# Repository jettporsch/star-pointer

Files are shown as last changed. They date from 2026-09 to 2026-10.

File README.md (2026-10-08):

# Star Pointer

A two-axis motorized mount that points a laser at any star you pick on your
laptop. It works out where to aim from your location, the current time, and a
two-star alignment done at setup.

**Status:** working prototype. After a two-star alignment it points the laser 
at a selected star, controlled from a phone or laptop. Next up is measuring 
accuracy across the sky and a cleaner v2 mount.

**Design target:** ±0.5° pointing accuracy.

## Why I built this

I've always been fascinated with space and astronomy, and I wanted a personal
project that used something I'm passionate about while digging into hardware.
This one covers embedded firmware, motion control, PCB design, mechanical
design, and enough math that the software side isn't just connecting 
libraries together.

## Architecture

This project splits into four jobs: find the star, know where the mount is
actually pointed, convert angles to steps, and generate the pulses.

Pulse generation has to be on the STM32 for microsecond timing and an
instant stop. The astronomy has to be on the laptop, because that's
where the catalog and the UI live.

Step conversion lives in Python for now. Two-star alignment needs the same 
math anyway, and prototyping it in Python was faster to debug. The firmware 
stays simple: it takes step moves, reports position, and handles the laser 
and stop. Porting the conversion to the STM32 is a possible later step.

The interface between the two sides is a small text command set over USB 
serial: move, status, stop, and laser.

```
  Laptop (Python)                    STM32                   Mechanics
  ---------------                    -----                   ---------
  star catalog          USB serial   command parser          NEMA 17 x2
  RA/Dec -> Alt/Az      -------->    step generation  ---->  4:1 GT2 belt
  two-star alignment    <--------    position count          alt-az fork
  angles -> steps        status      laser + auto-off        laser
  web UI (phone/laptop)              stop
```

## Repo layout

| Path | Contents |
|---|---|
| `app/` | Python host application |
| `firmware/` | STM32 firmware |
| `hardware/` | BOM, dimensions, CAD files, bench notes |
| `docs/` | Design decisions, error budget, serial protocol |

## Running the coordinate engine

Standard library only, no install step.

```bash
cd app
python3 skycoords.py        # current alt/az for every catalog star
python3 test_skycoords.py   # validation suite
```

## Running the mount

Needs Flask and pyserial: `pip3 install flask pyserial`.

```bash
python3 -m app.align   # desk test: simulated tilted mount, no hardware needed
python3 -m app.web     # web UI on http://localhost:8000
```

The web app listens on the local network, so a phone on the same wifi can open
it at the laptop's IP address on port 8000.

## Using it outside

1. Stage facing roughly south. That puts the cable limit (half a turn either
   way) due north, where few stars cross. The laser can rest at any angle.
2. 12V on first, so the motors lock the mount in place, then start the web app.
3. Jog the beam onto a bright star, sighting straight down the beam from behind
   the laser, pick it in the Align list, and tap "Beam is on this star."
4. The Align list now ranks every other star as a partner for the first one.
   Pick one rated "good" and do the same.
5. Tap any star in the list to point at it.

Choosing the second star matters more than it looks. With the same 0.1°
centering slip, a good pair keeps every GOTO within about 0.1°, while a poor
one can throw some off by several degrees. The app simulates each pair and
rates it, so there's nothing to memorize.

**Measuring accuracy:** after a GOTO, jog the beam onto the star and tap
"Centered." The app logs how far the GOTO landed from the star, and in which
direction, to `data/accuracy.csv`, and shows the RMS and worst miss for the
current alignment. Alignment stars are logged but left out of the stats.

Never point it at aircraft. The laser turns itself off 60 seconds after the
last command if the app goes away.

## Results so far

- **Step scale and backlash (wall test at 2.9 m):** 100 steps moved the beam
  2.8° on both axes, matching the gear math. Repeated moves with direction
  reversals landed back within about half a millimeter, under 0.01°.
- **First on-sky GOTO (Oct 6, 2026):** aligned on Altair and Vega from a
  driveway sloped about 4°. Alignment reported the base 3° off level and the
  laser's starting angle within 0.1°, both matching the real setup. GOTO to
  Deneb and Polaris landed on the star with no manual correction.
- **Not yet measured:** pointing error in degrees across the sky.

Details in `hardware/bench-notes.md`.

## Validation

The transform is checked against physical facts rather than against another
library. If a check fails, its name points at the specific thing that broke.
Comparing to a reference implementation would only tell me the two disagree,
not where or which one is wrong.

14 checks, all passing.

## References

Sidereal time, Julian date, and precession formulas follow Meeus,
*Astronomical Algorithms*. Refraction uses Bennett's formula.

## Progress

- [x] RA/Dec to alt/az transform, precession, refraction
- [x] Validation suite
- [x] STM32 stepper control, both axes
- [x] Altitude homing
- [x] Prototype mount built
- [x] Azimuth zero (manual index mark; switch homing kept as a test tool)
- [x] Serial protocol spec
- [x] Laser wiring and interlock
- [x] Laser auto-off timer
- [x] Two-star alignment
- [x] End-to-end GOTO
- [ ] Accuracy measurement across the sky
- [ ] v2 mount: smaller frame, cable routing, electronics enclosure
- [ ] Sidereal tracking
- [ ] Custom PCB

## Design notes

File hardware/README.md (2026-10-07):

Parts list in `bom.md`, measured part dimensions in `dimensions.md`, and a dated
log of every bench test in `bench-notes.md`.

CAD files in `cad/`: the full assembly as STEP, plus print files for the parts
changed most recently. No PCB yet; the electronics are on a breadboard.

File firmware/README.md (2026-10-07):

STM32 firmware for a Nucleo-F401RE. Toolchain: STM32CubeIDE.

Takes step moves over USB serial, runs both axes from hardware timers, and
switches the laser. Command set is in `docs/serial-protocol.md`.

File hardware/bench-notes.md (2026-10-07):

# Bench Notes

## 2026-09-15: First stepper test

The motor is rated at 1.5A. Coil pairs are black/blue and green/red.

The driver is a DRV8825 with R100 sense resistors, so I = Vref × 2. I set Vref to 0.595V, which is about 1.19A, 80% of the rating.

SLEEP floated low on this board, so SLEEP and RESET are tied to 3V3 on the Nucleo.

STEP is on PB4 and DIR is on PB5.

I tested one revolution forward and back at 5ms per step, and it worked.

The only problem I hit was that SLEEP floated low, which kept Vref reading 0 until it was tied to 3V3.

## 2026-09-15: Second stepper test

The second driver's Vref is 0.603V, which is about 1.21A. Its 12V, 3V3, and ground all come from driver 1's rows.

Motor 2 pins: STEP2 is on PB10 (D6) and DIR2 is on PA8 (D7). I renamed the first motor's pins to STEP1 and DIR1.

I moved the step loop into a step_motor() function.

Driver 1's heatsink got hot after running motor 1 for around a minute, so I left motor 1 unplugged while setting driver 2.

I tested both motors one revolution forward and back, and it worked.

## 2026-09-15: Serial link test

Serial runs over USART2 through the ST-Link USB at 115200 baud. I read it with screen on the Mac.

First I tested sending hello every second. Then I used keys 1 to 4 to move each motor forward or backward one revolution. The Nucleo replies with what it did.

I added a uart_print() helper.

## 2026-09-15: Hardware timer step pulses

I switched step pulses from bit-banging to hardware timers. TIM3 CH1 on PB4 drives motor 1 and TIM2 CH3 on PB10 drives motor 2.

The timer clock is 84 MHz. Prescaler 83 gives 1 MHz, and period 4999 gives 5ms per step at 50% duty.

An interrupt at the end of each pulse counts down the steps and stops the timer at zero. Each motor is an Axis struct.

I tested both motors moving at once, and that worked. A second command mid-move replies with busy.

CubeMX overwrote the STEP1/STEP2 labels when I assigned the timer channels.

## 2026-09-16: Serial command protocol

The firmware now reads full lines over serial, with echo and backspace.

Commands:
- `M <axis> <steps>` moves axis 1 or 2 by a step count, negative for reverse
- `S` reports position and busy for both axes
- `X` stops both axes

Replies are `OK`, `ERR <reason>`, or data.

Position counts in the step interrupt, so it stays accurate after a stop.

I tested `M` and `S` on both motors and they worked as intended. `X` stopped motor 1 mid-move and `S` reported the partial position. Bad axis and unknown commands both return errors.

## 2026-09-16: Python serial interface

I added `app/mount.py`, a Python class that talks to the Nucleo over serial. It wraps the firmware commands as `move`, `status`, `stop`, and `wait`, and turns `ERR` replies into Python exceptions.

The first test failed because Python and the firmware got out of sync. The firmware's line buffer had leftover characters from an earlier screen session, so the first command came back as `ERR unknown`. I fixed it by sending a bare Enter on connect to clear the buffer, and by having `send` skip the echo and blank lines instead of expecting the echo first.

After the fix I tested moves on both axes, `wait`, stopping mid-move, and a bad axis error. All worked. The DRV8825 heatsinks ran hot during testing.

## 2026-09-16: 1/16 microstepping

Both DRV8825s are now wired for 1/16 microstepping. Before this, M0 to M2 were floating, which is full step.

Nucleo 3V3 moved to its own breadboard rail. That rail powers SLEEP on both drivers and M2 on each driver. M0 and M1 on each driver are tied to ground.

At 1/16, 3200 steps is exactly one motor revolution. With the 4:1 belt reduction that works out to about 35.6 steps per degree at the output.

I put a piece of tape on each motor shaft and confirmed 3200 steps gives one full revolution on both motors.

## 2026-09-21: Lazy susan stack test

Printed the lid center section, 2mm spacer, and test turntable on the P2S and assembled them with the real lazy susan.

I used M5 x 25 countersunk screws on both rings, since both rings have countersinks. Washers under the nuts for stability. All eight screws went in freely, so the 107 and 82 bolt circles are confirmed.

The turntable spins freely with no rubbing. The inner ring screw heads are reachable from below through the 96mm lid opening, as long as the outer ring screws go in first. That is the only assembly order that matters.

## 2026-09-21: 608 bearing housing test

Printed the bearing housing and retainer and assembled with a 608-2RS. The bearing pressed into the 22.0 pocket by hand and seated on the shoulder. Retainer held with four M3 x 25 socket head screws, washers on both sides.

The bearing spins freely with no extra drag after assembly. The printed shoulder only touches the outer ring, not the seal. This housing design goes into the fork.

## 2026-09-21: Degree-based pointing

Added `app/pointer.py`, which takes altitude and azimuth in degrees and moves both motors to match. It uses 35.56 steps per degree (200 steps x 16 microsteps x 4:1 belt / 360). Targets are calculated from home every time so rounding error does not build up.

Azimuth stays between -180 and +180 from home and never crosses that point, so the cable loop cannot wind past its limit. Altitude is limited to 0 to 90. For now, wherever the motors are at connect counts as home. Endstop homing replaces that later.

Tested with tape flags on both motor shafts. 90 degrees at the output is exactly one motor rev, which matched on both axes. Going from az 90 to az 180 went backwards to -180 as intended. Altitude 95 was refused.

## 2026-09-21: Pointing at stars by name

Hooked `pointer.py` up to `skycoords.py`. `point_at("Vega")` now looks up the star, converts it to altitude and azimuth for Wylie at the current time, and moves both motors there. Stars below the horizon are refused.

For now, home has to be level and facing true north for the pointing to be right. Endstop homing and calibration handle that once the mount is built.

Tested with Vega, Arcturus, and Sirius. Vega's commanded and actual positions agreed within 0.012 degrees, which is under half a step, so the only error is rounding to whole steps. Sirius was below the horizon and was refused with no movement.

## 2026-09-21: Step speed

Added a `V <us>` serial command that sets the step period for both axes in microseconds, so speed can be tested live without rebuilding. Refuses changes while a motor is moving.

Tested one full rev at each speed with a tape flag, unloaded, no acceleration ramp:
- Motor 1: clean all the way down to 100us (10,000 steps/s)
- Motor 2: stalls at 100, hit or miss at 150, clean at 200 and up

A stalled motor makes noise but doesn't turn, and the firmware still counts the steps, so position is silently wrong. That's why the default has margin.

Default step period is now 600us at startup, 3x slower than motor 2's clean limit. That's about 47 degrees per second at the output, 180 degrees in about 4 seconds, down from 30 seconds before. To revisit once the mount is under real load, and after checking driver 2's Vref, which may explain the difference between motors.

## 2026-09-21: Web interface

Added `app/web.py`, a Flask app that runs on the laptop at localhost:8000. It lists all 22 catalog stars sorted by altitude with live alt/az, grays out stars below the horizon, points the mount when a star is tapped, shows live position, and has a stop button.

Moves start without blocking, and the page polls position twice a second, so stop works mid-move. A lock keeps requests from talking over each other on the serial port.

Tested in the browser: tapping Vega moved the motors there and the readout showed when it arrived. Stop halted a move immediately. Below-horizon stars can't be tapped. Speed at the 600us default feels right for pointing.

Correction to the step speed note: both drivers are set to nearly the same Vref (0.595V and 0.603V), so current doesn't explain motor 2's lower speed limit. Likely normal variation between motors.

Current UI is dark red for night vision. The plan later is a purple and yellow theme to match the mount's final look, with red kept as a night mode.

## 2026-09-22: Fork stage assembled

Printed and assembled the gusseted fork: two uprights with 608 bearings and retainers, slotted altitude motor plate with a spare NEMA 17, and the 196mm stage turntable, mounted on the lazy susan and lid center test.

The shaft passes through both bearings and turns freely with the feet tightened. Shaft collars on each side stop it sliding. Both pulleys reach their specified positions and their tooth bands line up. No visible flex at the top of the uprights under hand pressure. Belt tension is reasonable with the motor near mid-slot.

Ordered the 280mm GT2 belt, which is the calculated length for the 88mm center distance the slots are built around.

Next is the laser cradle.

## 2026-09-22: Laser control

Added `L 1` and `L 0` serial commands to switch the laser on and off through PA9 (D8 on the header). The pin starts low at power-up, so the laser is off until it's deliberately turned on. `axis_stop_all` also drives it low, so the stop command kills the beam along with the motors.

Tested with a multimeter on D8: 3.3V after `L 1`, 0V after `L 0`, and 0V after `X`.

The laser itself needs more current than a GPIO pin can supply, so it switches through an NPN transistor with a 1k resistor on the base, laser red to 5V and black to the collector. Transistor and resistor kits are ordered. The firmware side is done and waiting on parts.

## 2026-09-22: Laser cradle

Printed and fitted the laser cradle. It clamps the 8mm rod with the lower cap and holds the laser module with the upper cap. Both use the bore sizes from the coupon tests, 8.2 for the rod and 12.0 for the laser.

Rotated the rod a full 360 degrees with the laser mounted and nothing contacts the uprights, belt, or pulley. Altitude only needs 0 to 90, so there's plenty of room.

The specified screws are longer than needed and stick out past the nuts. Cosmetic, swapping for shorter ones.

## 2026-09-22: Altitude home assembly

Installed the altitude home hardware on the left upright: a bracket that bolts over the existing bearing retainer using the same four screws, an adjustable switch carrier, and a cam that clamps to the rod outside the fork.

It works as intended. The cam reaches the lever and the carrier slides to set the trip height.

The carrier is still adjustable because I don't know this switch's actual sensitivity yet. Next step is measuring the real trip point, release point, and how much lever travel is left before it bottoms out, using a multimeter across the switch contacts. Those numbers set the cam lift and let the carrier height be fixed in the next revision instead of adjustable.

## 2026-09-23: Altitude drive powered test

Fitted the 280mm GT2 belt between the 20T motor pulley and the 80T shaft pulley and ran the altitude axis under power for the first time.

Started slow at 2000us with small moves, then worked up. 3200 steps gives 90 degrees of tilt, which matches the 35.56 steps per degree from the 4:1 reduction. Moving out 3200 and back 3200 returned the laser to a tape mark, so no teeth were skipped. Motion is smooth, the belt tracks without rubbing, and nothing catches through the range.

## 2026-09-23: Altitude endstop reading

Added an `E` command that reports endstop state over serial. The altitude switch is on PA10 (D2) with an internal pull-up.

The endstop boards have their own 10K pull-up, LED, and debounce cap, wired out to S, G, V. Wired G to ground, S to D2, and V to 3V3. With that board, the pin reads high when the lever is free and low when pressed, so the firmware inverts it. `E` now reports 0 for free and 1 for triggered.

Tradeoff worth noting: going through the board's S pin means a disconnected wire reads as not triggered, so homing would keep driving. Wiring S straight to the switch's NC pin instead would fail toward stopping, at the cost of the board's LED and debounce. Keeping the current wiring while homing is supervised on the bench.

Next step is using `E` to find the exact step count where the cam trips, which sets level zero without measuring by hand.

## 2026-09-23: Altitude homing

Installed the V2 fixed home bracket, carrier, and cam. Homing approaches level from below, because coming down the lever tip catches the cam's clamp slot. The cam is clamped so the switch trips exactly at level, set with a level while the motor held position.

Added an `H` command. It backs off below the cam if already on it, drives up until the switch trips, backs off 400 steps, then creeps up at 6000us in 5-step increments and calls the first trip zero. Worst case overshoot is 5 steps, 0.14 degrees. Each search is bounded, so a disconnected switch errors out instead of driving on.

Tested repeatedly from different starting positions below level and it lands level each time.

Also found the 600us default step speed is too fast now that the cradle, laser, and belt are on the axis. It stalls starting from rest. 2000us works. Acceleration ramps would let it run faster and start reliably, worth doing later.

Shaft collars installed inside the fork, one against each bearing, with no added drag.

Note on procedure: the cam is the harder thing to set and the cradle is the easier one, so it would be better to treat the cam as the fixed reference and level the cradle against it, rather than the reverse. If anything slips, home first, then loosen the cradle and level the laser to the cam's edge.

## 2026-10-04: Azimuth endstop debugging

The azimuth endstop read 0 no matter what. Two separate faults stacked on top of each other.

First, both endstops went dead at once. The 3V3 wire feeding the endstop boards had worked partly out of the breadboard. Reseating it brought altitude back.

Second, the azimuth pin was wrong in firmware. PB2 was listed as D10, but D10 on the Nucleo-F401RE is PB6. PB2 is only on the Morpho header, so the firmware was reading a pin with nothing attached, and the internal pullup held it high forever. Moved the config to PB6 in CubeMX, changed AZ_ES_PIN to GPIO_PIN_6, and left the wire on D10. E now reports AZ correctly from the lever.

Third, mechanical. With the electrical path working, the cam lobe turned out to be about 1mm short of pushing the lever to its trip point. Contact happens but never clicks. Reprinting the cam with 1mm more lift at the lobe peak. The lever has about 1mm of overtravel past the trip, so 1mm more lift should trip without bottoming it.

Next after the reprint: confirm the trip in both rotation directions, measure how many degrees the lobe stays triggered, then write the azimuth homing routine. Unlike altitude's wide plateau, this cam has a single bump so the switch is off for most of a revolution.

## 2026-10-04: Azimuth cam reprint and homing

The reprinted cam with 1mm more lift trips the switch, and the lever doesn't bottom out on the lobe peak.

The az belt had too much sag with the motor on the adjustable slides. Next revision of the az motor mount should be a fixed position, slightly farther back, instead of slotted.

STEP2 dropped out twice. M 2 replied OK and S counted the steps, but the motor was silent and didn't turn. The connection between D6 and driver 2's STEP pin was intermittent. Reseating fixed it once, then it came back, so I replaced the jumper and pressed driver 2 down into the breadboard. Breadboard contacts keep causing problems, the drivers should go on a soldered board eventually.

Positive az steps turn the stage clockwise looking down.

Added `app/az_cam_sweep.py`. It steps az 5 steps at a time, checks E after each, and logs every switch edge forward then back. Currently set to a 120 degree sweep.

Results: the lobe is about 80 degrees wide (on from 2649 to 5489 going CW, 5264 to 2434 going CCW). There's about a 6 degree gap between directions on both edges (215 and 225 steps). That could be switch hysteresis or belt backlash, this test can't separate them. The CW trip edge was clean. The release edge was less consistent and chattered once.

The cables went tight near the end of the 120 degree sweep. Moved things closer for more slack. Az needs a full 360 degrees of cable travel with home in the middle.

An 80 degree lobe only partly fixes the power-up direction problem. Switch on means you know where you are, switch off covers the other 280 degrees and is still ambiguous. Next cam revision is a half-moon: same lift, same ramp on the CW-trip edge, raised section stretched to 180 degrees. Then the switch state at power-up tells homing which way to go.

Added an `H AZ` command. If on the lobe, it drives CCW until it releases and backs off 400 more. Then it searches CW until it trips, backs off 400, and creeps CW one step at a time to the trip edge, which is zero. `HOMED` prints where the old count thought the edge was before zeroing, so repeatability shows up directly. `H` still homes altitude.

Fixed a bug where `move_wait` skipped moves if the axis was still busy from a previous command.

Repeatability is about plus or minus 13 steps, roughly 0.38 degrees, over 6 homes from both sides. The error budget has 0.05 degrees for homing. Either the switch trip point is that loose because the cam ramp is shallow, or steps are getting lost somewhere. A fixed home offset gets absorbed by two-star alignment, so this only matters when re-homing without realigning.

Next: laser on a wall about 3m away to see if the stage physically stops in the same spot each home. Same spot with scattered HOMED numbers means lost steps. Spot moving means the switch.

## 2026-10-05: Half-turn az cam and fixed az motor plate

Printed and installed the new az home cam. Same 18.5mm peak radius, raised section stretched to about half a turn, and the CW home ramp shortened from 65 to 20 degrees so the switch trips on a steeper part of the ramp. The other ramp stays at 65 degrees. The lever rides it smoothly in both directions by hand.

Replaced the slotted az motor plate with one that has round holes instead of slots, reusing both rails. That puts the motor shaft at a fixed 72.8mm from the center shaft: 72.5mm nominal for a GT2-250 belt on 20T and 80T pulleys, plus 0.3mm for tension. The V-notch on the plate faces away from the center shaft. Belt is snug.

Cleaned up some of the wiring.

Added the current full assembly STEP and the two new print files to `hardware/cad/`.

Expected: the new ramp is about 3x steeper where the switch trips, so if the homing scatter is coming from the switch, the ±0.38 degrees should drop to around ±0.12 and the 6 degree direction gap to about 2. Not tested yet.

Next: power up, measure the new switch window, rerun homing repeatability, then the laser wall test.

## 2026-10-05: Laser wired, az switch homing dropped

Mapped the new half-turn cam with `app/az_walk.py`. Going CCW, the switch releases cleanly off the steep ramp. Going CW back up the steep ramp, it doesn't click on until about 34 degrees onto the flat top. On the flat top the lever is pushed far enough to hold the switch on but not far enough to click it on, so the old homing routine, which expected a click on the steep ramp, got stuck. Compared the cam STEP to the previous +1.0mm cam: same 14.5/18.5mm radii, rim, height, and clamp, so the file isn't the cause. The switch is acting about half a mm farther out than with the old cam.

Rewrote `H AZ` to home on the CCW release edge instead. It works, but the HOMED numbers drifted about 70 steps when starting from off the cam. A test of plain moves (four ±3000 step round trips, then home) came back 42 steps off, within homing scatter, so normal moves aren't losing steps.

Dropped switch homing for az. It only locates the stage relative to the base, and two-star alignment handles where it points in the sky every session. The only real job left is cable management, which an index mark does. For now az zero is a pencil mark on the base and stage, lined up before power-on. Later, a penny-width slot in the turntable rim and lid will lock it in place. `H AZ` stays in the firmware as a test tool. Alt homing stays.

Wired the laser through a 2N2222: D8 to a 330 ohm resistor to the base, emitter to GND, collector to the laser's black wire, laser red to 5V. Used 330 instead of the 1k planned earlier because green diodes can pull 100+mA and 1k only switches about 25mA cleanly. `L 1` turns it on at full brightness, same as wired straight to 5V. `L 0` turns it off, and `X` kills it.

Next: laser auto-off timer, alt homing on connect in pointer.py, jog controls, two-star alignment.

## 2026-10-06: Wall test and laser auto-off

Unplugged both endstops. The firmware only reads them during H, H AZ, and E, and both pins have pull-ups, so unplugged they just read as not pressed.

Wall test with the laser on the mount, about 114.5 inches (2.91m) from the wall. 100 steps on az moved the dot 144.6mm both directions. Expected 143mm, the difference is because I measured from the laser tip, which sits a few cm in front of the az axis. 100 steps on alt moved it 142.99mm both directions, matching the expected 143mm. After repeated back-and-forth moves on both axes, including direction reversals, the dot landed back on its marks within about half a mm, which is under 0.01 degrees. Step scale is correct on both axes and backlash is too small to measure. The 6 degree gap from the old az switch tests was switch hysteresis, not the belt.

Added a laser auto-off: the laser turns off on its own 60 seconds after the last L 1. It turns off silently so the host doesn't read an unexpected line as the reply to its next command. Tested, it shuts off at about a minute.

Next: jog controls in the web app, then two-star alignment.

## 2026-10-06: First on-sky GOTO

Tested in the driveway, which slopes about 4 degrees. Startup: stage facing roughly south, laser laid flat, 12V on, then the web app.

First attempt failed because the laser wasn't flat at startup (alt zero came out 47 degrees off, outside the solver's search range), and the az stage could be turned by hand while the motor was holding. The 80T pulley wasn't gripping the center shaft. A long az slew fell short, and every move after that carried the error forward. The app was commanding the right moves, the stage just didn't follow. The earlier wall test only used short moves, so it didn't catch this. Tightened it.

Second attempt: aligned on Altair and Vega, sighting straight down the beam from behind the laser. Alignment reported the base about 3 degrees off level and alt zero within 0.1 degrees, both matching the real setup. GOTO to Deneb, Polaris, and back to Vega all landed on the star with no jog correction needed.

Lessons: 12V on before starting the app so the laser can't swing, sight down the beam when centering, and face south at startup so the cable limit sits due north where few stars cross.

Next: big round-trip az test indoors to confirm the pulley stays tight, then measure accuracy across more stars.

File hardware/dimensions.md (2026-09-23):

## Printed fits (Bambu P2S, 0.4mm nozzle)

Found with fit-test coupons. Design to these values.

| Feature | Design value | Hardware |
|---|---|---|
| 608 bearing seat | 22.0 | 22.0 OD |
| Laser clamp bore | 12.0 | 12.0 OD |
| Shaft clamp bore | 8.2 | 8.0 rod |
| M3 clearance | 3.0 | M3 |

Motor coupon: sits flat, slides freely in 3.4 wide slots.

## Lazy susan bolt circles

Found with printed test rings. Provisional until the real mount is tested.

- Inner ring: 82 bolt circle, 5mm holes
- Outer ring: 107 bolt circle, 5mm holes, countersunk
- Inner ring OD ~93.5, outer ring ID ~95.3
- Both rings flush on both faces with pads removed

## Pulley tooth bands

Measured hub face down.

- 20T: 15.8 tall, teeth from 7.5 to 14.8
- 80T: 18.14 tall, teeth from 8.75 to 16.24

## Hardware measurements (calipers)

- NEMA 17: 42.3 face, 31.0 bolt spacing, M3, 22 boss x 2 tall (standard). Body 37.5 long. Shaft 5mm with D-flat, 21.5 long
- 608 bearing: 22 OD, 8 ID, 7 thick (standard)
- Altitude shaft: 8mm rod, 300 long
- 20T pulley: 5mm bore, ~15.9 flange OD
- 80T pulley: 8mm bore, ~55.1 flange OD
- Lazy susan: 120.13 OD, 70 center opening, 8.5 thick with pads removed
- Endstop: 20 x 20 board, 3mm holes, 15 spacing
- Laser: 12 dia x 38 long, 3 to 5V

## Endstop switch

Board is 20 x 20 with 3mm holes on 15mm centers. Switch body 12.85 wide, lever about 13 long. Pins labeled C, NO, NC.

Lever travel, measured with calipers:
- Total travel from free to fully pressed: about 3mm
- Trips at about 2mm of travel
- About 1mm of overtravel left after the trip

Cam lift should be about 2.5mm: past the trip point with margin, without bottoming the lever.

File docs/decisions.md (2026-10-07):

# Design decisions

One entry per real decision: what I chose, what I rejected, and why. Written
when the decision is made, not reconstructed afterward.

The point is to be able to answer "why did you do it that way" months later
without guessing at my own reasoning.

## D1. Alt-az mount, not equatorial

**Chose:** two-axis altitude/azimuth mount.

**Rejected:** equatorial mount.

**Why:** an equatorial mount's advantage is smooth single-axis tracking, which
matters for long-exposure astrophotography. I'm pointing a laser, so that buys
me nothing. In exchange I'd be taking on a tilted frame that makes the
coordinate math messier, plus a counterweight and a mount angled to my
latitude. Re-pointing every 10 seconds works fine on two axes.

## D2. STM32, not Arduino

**Chose:** STM32 (Nucleo-F401RE).

**Rejected:** Arduino.

**Why:** Arduino has a shallower learning curve, but it abstracts away the
hardware I want to work at. I already have STM32 experience from a previous
project, so my time goes into motion control instead of learning a new
toolchain. The STM32's hardware timers generate step pulses without CPU
involvement, which is what makes precise stepping possible. It also keeps the
project at the register and peripheral level.

## D3. Belt reduction, 4:1

**Chose:** GT2 belt, 20-tooth motor pulley to 80-tooth output pulley, on both
axes.

**Rejected:** direct drive; 3D printed spur gears; 5:1 with a 100-tooth pulley.

**Why:** direct drive makes 1.8° the finest possible move, and my pointing
budget is ±0.5°, which takes it off the table immediately. Microstepping
doesn't fix this. The rotor still settles toward the nearest full step under
load, so it buys smoothness, not accuracy.

Gearing down solves it mechanically. At 4:1, one full step at the motor becomes
0.45° at the output, and the reduction divides load-induced error by four as
well.

I went with belts rather than 3D printed gears because layer lines on a printed
tooth face give a degree or more of backlash. A tensioned GT2 belt is nearly
backlash-free.

I originally specced 5:1, but 100-tooth pulleys are rare and expensive in
aluminum, and printing one would put me back in backlash territory. 80-tooth is
common and cheap, and 80 against my 20-tooth motor pulley is 4:1.

## D4. Two-star alignment, not a magnetometer

**Chose:** manual two-star alignment.

**Rejected:** magnetometer for heading.

**Why:** a magnetometer is cheap, but it reads magnetic north, and true north
is about 2° off from that in North Texas. That correction is easy. The real
problem is that it would sit inches from two stepper motors and a steel frame,
so my own hardware corrupts the reading and no correction fixes that.

With two-star alignment I manually slew to two stars I can identify, confirm
each one, and the app records the motor positions. From those two
observations it solves for how the mount is actually oriented. One procedure
handles heading and leveling at once, so a tripod that's 1° out of level gets
absorbed instead of costing me up to 1° of pointing error.

The cost is that it's a manual step at every setup, and I have to be able to
identify two stars.

## D5. DRV8825 stepper drivers

**Chose:** DRV8825.

**Rejected:** A4988, TMC2209.

**Why:** the DRV8825 is pin-compatible with the A4988 but handles more current
with finer microstepping, at the same price. The TMC2209 is nicer on paper,
mainly for sensorless homing, but that is unreliable on a low-torque belt axis,
and homing turned out to be unnecessary anyway (see D7).

## D6. Mount position and step conversion live on the STM32

**Chose:** the laptop sends an alt/az pair. The STM32 applies the alignment,
converts to steps, and tracks its own position.

**Rejected:** the laptop computing step counts and sending those instead.

**Why:** if the laptop kept its own copy of mount position, a missed step or a
restarted app would make the two disagree with nothing to catch it. Keeping one
authority, on the thing bolted to the motors, removes that class of bug. The
laptop never needs to know about steps, gear ratios, or microstepping. All it
does is name a direction, which also means anything that can send an alt/az
pair could drive the mount.

The cost is more C, and firmware debugging is slower than Python. I'm
mitigating that by prototyping the alignment math in Python first, then porting
it to C with known-good numbers to check against.

**Revised, Oct 2026:** step conversion and alignment ended up in Python, and
the firmware only takes step moves. Once alignment was written in Python, it
already had to do the angle math, and splitting it across two languages bought
nothing. The missed-step concern above is real but didn't show up: the wall
test came back within 0.01° after repeated moves, and the one real failure on
the sky (a slipping pulley) was mechanical, so neither side's count would have
caught it. Porting to C is still an option, not a requirement.

## D7. No limit switch homing

**Chose:** start with the stage on a pencil mark and the laser roughly flat,
then let two-star alignment work out the rest.

**Rejected:** endstop homing on both axes.

**Why:** two-star alignment solves for where az zero points, how far off level
the base is, and how far off flat the laser started, every session. Homing only
told the mount where it was relative to its own base, which alignment throws
away anyway. The only real job left was keeping the cables from winding past
their slack, and an index mark does that.

I built and tested switch homing first. Altitude worked. Azimuth took days of
cam reprints and still scattered about ±0.4°, and most of the 6° hysteresis I
measured turned out to be the switch itself, not the drive. That effort was the
signal to step back and ask what homing was actually for.

**Cost:** two rules at startup (stage on the mark, laser roughly flat, 12V on
before the app). A slot that locks the turntable with a coin is on the v2 list
to make the az mark more precise.

## Template

```
## Dn. Title

**Chose:**
**Rejected:**
**Why:**
```

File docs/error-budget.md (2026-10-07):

# Pointing error budget

**Target: ±0.5° total pointing error, anywhere above 20° altitude.**

## Why 0.5 degrees

This comes from what a person can see. The full moon is about 0.5° wide, so a
laser that lands within a moon's width of the intended star reads as a hit to
anyone standing there watching. Tighter than that doesn't buy a visible
improvement and would cost a lot of mechanical precision. Looser and it would
obviously be missing the star.

It's also achievable with the parts I bought, but not by much: 0.39° estimated
against the 0.5° target, leaving about 0.11° of headroom. Some of the terms in
that estimate are computed from the step size and gear ratio, but the
mechanical ones are engineering estimates until I measure them.

## How the errors combine

Independent errors don't add straight, they combine as root sum square. They're
independent, so they don't all push the same direction at the same moment.
Backlash might pull me left while flex pushes me right.

The consequence is the useful part. Take a 0.25° error and a 0.05° error.
Straight addition gives 0.30. RSS gives 0.255. The small one contributed almost
nothing.

So one large term dominates the total and shaving the small ones is wasted
effort. My biggest is alignment residual at 0.25°, and halving my smallest term
would move the total by about 0.001°. That's the rule the rest of this document
runs on: go after the biggest term, ignore anything under about 0.05°.

## Budget

| # | Source | Estimate | Measured | Notes |
|---|---|---|---|---|
| 1 | Microstep positional error | 0.07° | tbd | ±0.2 full step at motor, divided by 4 at the belt |
| 2 | Belt backlash and compliance | 0.15° | <0.01° | Wall test at 2.9 m, repeated moves with reversals |
| 3 | Frame and printed-part flex | 0.15° | tbd | Estimate, worst at high altitude |
| 4 | Two-star alignment residual | 0.25° | tbd | First sky test: GOTO landed on Deneb and Polaris by eye, not yet measured in degrees |
| 5 | Laser collimation offset | 0.15° | tbd | Estimate, beam axis vs altitude axis |
| 6 | Homing repeatability | 0.05° | n/a | Switch homing dropped (decision D7); alignment absorbs the start position |
| 7 | Coordinate math residual | 0.02° | 0.01° | Measured by the test suite |
| 8 | Clock error | 0.01° | n/a | Sky moves 0.25°/min, so 1 s of clock error is 0.004° |
| 9 | Observer position error | <0.01° | n/a | 0.001° of latitude is about 100 m |
| | **RSS total** | **0.39°** | | |

## Errors already eliminated

| Source | Would have cost | How it was removed |
|---|---|---|
| Neglecting precession | 0.15 to 0.37° | Applied IAU 1976 precession to epoch of date |
| Neglecting refraction | 0.02° at 45°, 0.5° at horizon | Applied Bennett's formula |
| Tripod not level | up to 1.0° per degree of tilt | Absorbed by two-star alignment |
| Magnetic declination | about 2° in North Texas | No magnetometer, heading comes from alignment |
| Direct-drive step size | 1.8° | 4:1 belt reduction |

## How each term gets measured

**Repeatability.** Command a slew away from a target and back, 20 times.
Measure how much the laser spot scatters on a wall at a known distance. Spot
displacement over distance gives the angle directly: 1 cm at 10 m is 0.057°.

**Backlash.** Approach the same target from clockwise, then from
counterclockwise. The difference between the two spot positions is the
backlash.

**Alignment residual.** Align on two stars, then command a third known star and
measure how far off it lands. Repeat across different parts of the sky. This is
the only one that needs a clear night.

## Rules

- Don't chase a term below 0.05°. At that level it contributes under 2% of the
  RSS total and the measurement itself is not that good.
- Update the Measured column as tests happen. An estimate that was never
  checked is not a budget, it is a guess.
- If the measured total exceeds 0.5°, either fix the dominant term or move the
  target and say so.

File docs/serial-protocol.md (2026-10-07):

# Serial protocol

USB serial (the Nucleo's ST-LINK virtual COM port), 115200 baud, 8N1. Commands
are plain text lines ending in CR or LF. The firmware echoes each character as
it's typed, so a terminal like `screen` works for manual testing. The Python
side skips the echo and reads the next non-empty line as the reply.

Every command gets exactly one reply line. Errors start with `ERR`. The
firmware never sends anything unprompted except `star pointer ready` at
startup, so the host can always pair a reply with the command that caused it.

Axis 1 is altitude, axis 2 is azimuth. Positive altitude raises the beam,
positive azimuth turns the stage clockwise seen from above. One step is a 1/16
microstep: 200 x 16 x 4 / 360 = 35.56 steps per degree at the output.

## Commands

| Command | Reply | What it does |
|---|---|---|
| `M <axis> <steps>` | `OK` | Relative move. Returns right away; the move runs in the background. Both axes can move at once. |
| `S` | `POS <alt> <az> BUSY <alt> <az>` | Step counts since power-on, and whether each axis is still moving (1 or 0). |
| `X` | `OK` | Stop both axes and turn the laser off. |
| `V <us>` | `OK` | Step period in microseconds, 100 to 20000, both axes. Power-on default is 600. The host sets 2000 because the loaded az stage can stall faster. |
| `L 1` | `OK` | Laser on. It turns itself off 60 s later unless `L 1` is sent again. |
| `L 0` | `OK` | Laser off. |
| `E` | `ES ALT <0/1> AZ <0/1>` | Endstop states, 1 means pressed. Reads 0 with the switches unplugged. |
| `H` | `HOMED` | Altitude homing on its endstop. Optional, see decision D7. |
| `H AZ` | `HOMED <n>` | Azimuth homing test routine. `n` is where the count thought the edge was before zeroing. Kept as a test tool. |

## Errors

| Reply | Cause |
|---|---|
| `ERR busy` | `M` sent to an axis that is still moving, or `V` sent while either axis moves |
| `ERR bad axis` | Axis not 1 or 2 |
| `ERR bad period` | `V` outside 100 to 20000 |
| `ERR unknown` | Unrecognized command |
| `ERR no switch`, `ERR no release`, `ERR no edge`, `ERR stuck on` | Homing could not find the switch edge it expected |

## Laser timeout

The 60 s auto-off is a dead-man switch. While the web page is open with the
laser on, the app re-sends `L 1` every 10 seconds. If the page, the laptop, or
the USB cable goes away, nothing re-arms it and the beam goes off on its own.
It turns off silently on purpose: an unprompted message would be read as the
reply to the host's next command.

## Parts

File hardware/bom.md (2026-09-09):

# Bill of materials

## Ordered

| Qty | Item | Spec | Source |
|---|---|---|---|
| 1 | STM32 Nucleo-F401RE | STM32F401RET6, onboard ST-Link | DigiKey |
| 4 | 100 µF 50 V electrolytic | Panasonic EEU-FR1H101B, low ESR | DigiKey |
| 10 | 0.1 µF 50 V X7R ceramic | Kemet C320C104K5R5TA, 2.54 mm pitch | DigiKey |
| 2 | 470 µF 35 V electrolytic | Panasonic EEU-FM1V471 | DigiKey |
| 3 | NEMA 17 stepper | 1.5 A, 42 N·cm, 42x42x38 mm | Amazon |
| 5 | DRV8825 driver module | With heatsink | Amazon |
| 6 | GT2 pulley, 20T | 5 mm bore, 6 mm belt | Amazon |
| 1 | GT2 pulley kit, 20T and 80T | 8 mm bore, with 250 mm belts | Amazon |
| 5 | GT2 closed loop belt | 110/200/300/400/610 mm, 6 mm wide | Amazon |
| 5 | Mechanical endstop | 3-pin, with LED and pull-up | Amazon |
| 1 | 12 V 5 A power supply | 5.5x2.1 mm barrel, screw terminal adapter | Amazon |
| 6 | LM2596 buck converter | Adjustable, 3 A | Amazon |
| 10 | 608-2RS bearing | 8x22x7 mm | Amazon |
| 1 | Lazy susan bearing | 4 inch aluminum | Amazon |
| 2 | Linear shaft | 8 mm x 400 mm hardened steel | Amazon |
| 1 | M3 hardware assortment | 6 to 30 mm, nuts and washers | Amazon |
| 1 | Breadboard and jumper kit | 830 tie points | Amazon |
| 1 | Multimeter | Klein MM325, CAT III 600 V | Amazon |

## Still to order

| Item | Notes |
|---|---|
| Green laser module | 5 mW, Class 3R |
| MOSFET and gate resistor | Laser switching |
| Momentary pushbutton | Dead-man switch |
| PCB fabrication | After the breadboard design is proven |
| Camera tripod | Any 1/4-20 tripod works as the base |

## Notes

**Power.** 12 V for the motor rail, 5 V stepped down for logic, common ground.
The 100 µF bulk cap goes physically at each driver's VMOT pin, not somewhere
convenient on the rail. The DRV8825 datasheet is explicit about this and
skipping it is a known way to kill the driver.

**Current limit.** Set Vref before connecting a motor. My motors are rated
1.5 A but the DRV8825 with a stick-on heatsink handles about 1.5 A at best, and
this application has almost no load, so around 1 A is the target. Getting it
wrong overheats the motor and causes missed steps, which will look like a
firmware bug and waste a day.

**Laser safety.** Class 3R green is the astronomy standard. Planned interlocks:
momentary dead-man switch, firmware timeout, laser disabled while slewing, and
a minimum altitude cutoff. Pointing a laser at aircraft is a federal offense,
so this does not get operated near an approach path.

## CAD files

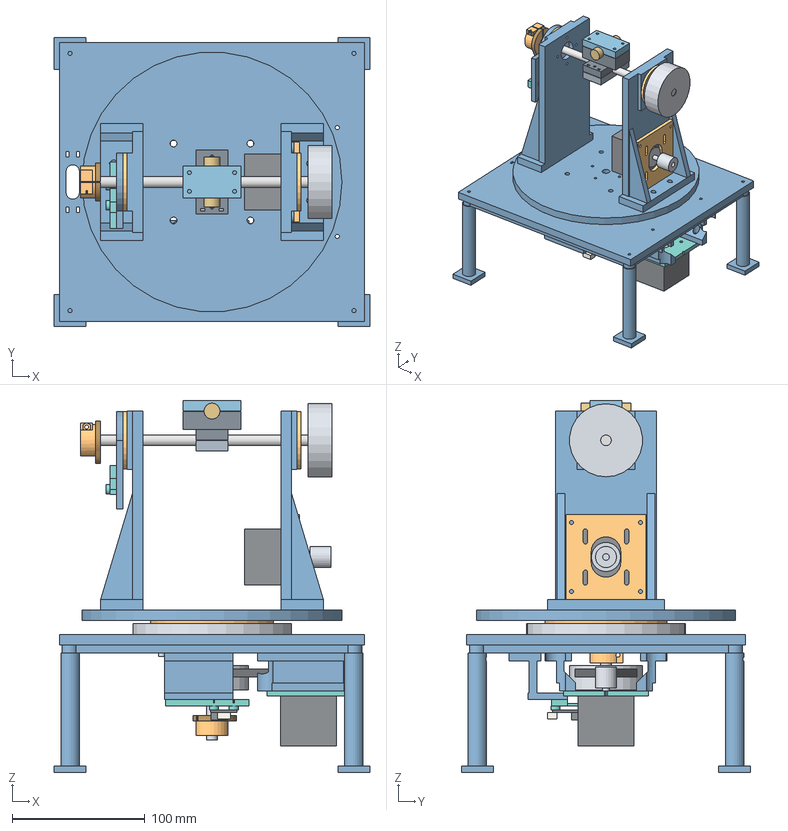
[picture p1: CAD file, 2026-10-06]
hardware/cad/assembly.step
238.0 x 218.0 x 280.5 mm
AZ__01_Full_Lid
AZ__02_Long_Shaft_Hub
AZ__04_Motor_Rail_PosY
AZ__04_Motor_Rail_NegY
AZ__05_Azimuth_Switch_Hanger
AZ__08_Bench_Stand_1
AZ__08_Bench_Stand_2
AZ__08_Bench_Stand_3
AZ__08_Bench_Stand_4
AZ__REUSE_196mm_Turntable
AZ__REUSE_2mm_Inner_Spacer
AZ__REF_Inner_Ring
AZ__REF_Outer_Ring
AZ__REF_Outer_M5_Shank_0
AZ__REF_Outer_M5_Washer_0
AZ__REF_Outer_M5_Nut_ENVELOPE_0
AZ__REF_Outer_M5_Shank_1
AZ__REF_Outer_M5_Washer_1
AZ__REF_Outer_M5_Nut_ENVELOPE_1
AZ__REF_Outer_M5_Shank_2
AZ__REF_Outer_M5_Washer_2
AZ__REF_Outer_M5_Nut_ENVELOPE_2
AZ__REF_Outer_M5_Shank_3
AZ__REF_Outer_M5_Washer_3
AZ__REF_Outer_M5_Nut_ENVELOPE_3
AZ__REF_8mm_Shaft_90mm
AZ__REF_80T_Pulley_ENVELOPE
AZ__REF_8mm_Collar_14OD_7wide
AZ__06_Azimuth_Switch_Carrier_V6_Actual_Board_Left
AZ__Actual_Board_Reference
AZ__Switch_Body_Reference
AZ__Connector_Reference
AZ__Resting_Lever_Reference
ALT_FORK__PRINT_Left_Fork
ALT_FORK__PRINT_Right_Fork
ALT_FORK__PRINT_Motor_Plate
ALT_FORK__PRINT_Left_Retainer
ALT_FORK__PRINT_Right_Retainer
ALT_FORK__REF_Left_608
ALT_FORK__REF_Right_608
ALT_FORK__REF_Motor_Body
ALT_FORK__REF_Motor_Boss
ALT_FORK__REF_Motor_Shaft
ALT_FORK__REF_80T_Flange_Envelope
ALT_FORK__REF_20T_Flange_Envelope
ALT_HOME__01_Fork_Home_Bracket
ALT_HOME__02_Fixed_Switch_Carrier
ALT_HOME__03_Split_Shaft_Cam
CRADLE__01_Cradle_Body
CRADLE__02_Shaft_Clamp_Cap
CRADLE__03_Laser_Clamp_Cap
REF__Altitude_Shaft_180mm_SCHEMATIC_NOT_CUT_LENGTH
REF__Laser_12x38mm_Envelope
AZ__03_Fixed_Motor_Plate_72p8_REUSE_RAILS
AZ__07_Half_Turn_Cam_CW_20deg
AZ__REF_Motor_Body
AZ__REF_Motor_Boss
AZ__REF_Motor_Shaft
AZ__REF_20T_Pulley_ENVELOPE
AZ__REF_GT2_250_Belt_Tensioned_Envelope

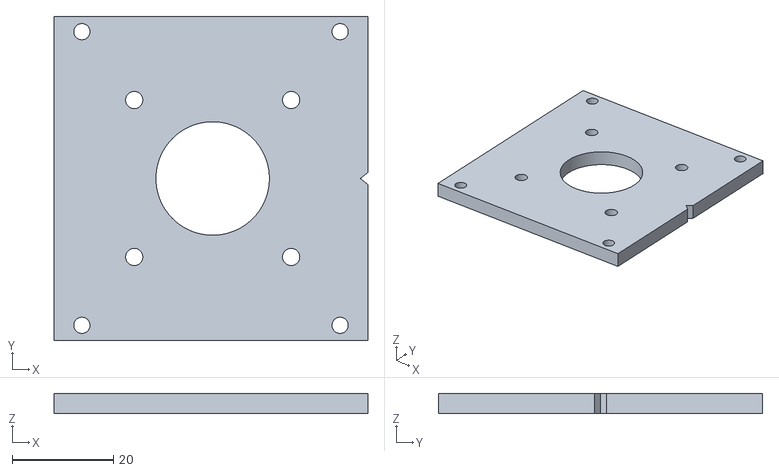
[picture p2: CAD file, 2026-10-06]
hardware/cad/az-motor-plate.stl
62.0 x 64.0 x 4.00

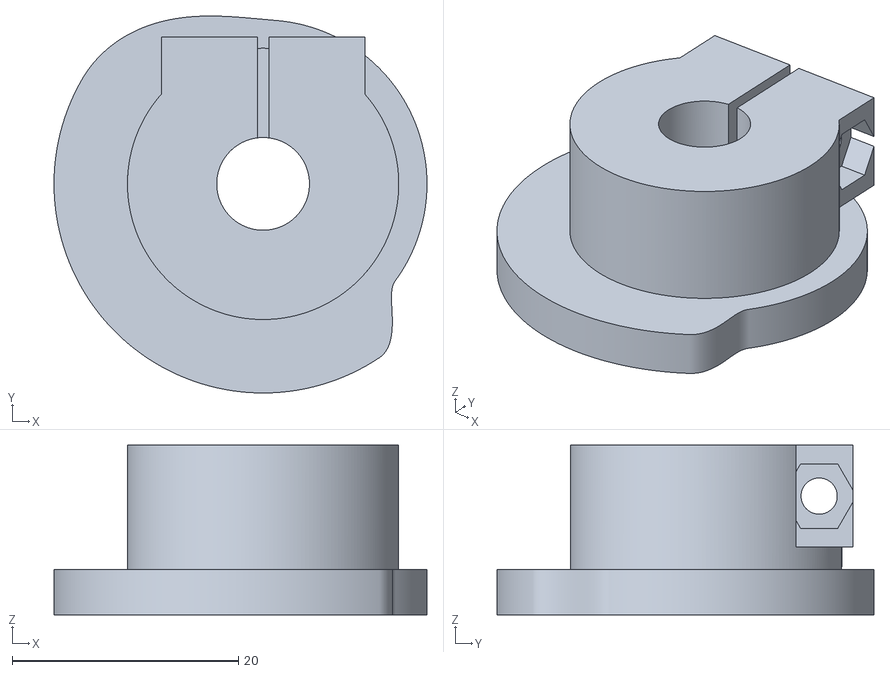
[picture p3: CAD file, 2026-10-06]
hardware/cad/az-home-cam.stl
33.0 x 33.3 x 15.0

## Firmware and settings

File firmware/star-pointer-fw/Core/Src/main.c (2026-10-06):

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
/* Includes ------------------------------------------------------------------*/
#include "main.h"
#include "tim.h"
#include "usart.h"
#include "gpio.h"

/* USER CODE BEGIN Includes */
#include <string.h>
#include <stdio.h>
/* USER CODE END Includes */

/* USER CODE BEGIN PTD */

typedef struct {
  TIM_HandleTypeDef *htim;
  uint32_t channel;
  GPIO_TypeDef *dir_port;
  uint16_t dir_pin;
  volatile uint32_t steps_left;
  volatile uint8_t busy;
  volatile int32_t pos;
  int8_t dir;
} Axis;

/* USER CODE END PTD */

/* USER CODE BEGIN PD */


#define LASER_PORT GPIOA
#define LASER_PIN  GPIO_PIN_9

#define LASER_TIMEOUT_MS 60000

#define ALT_ES_PORT GPIOA
#define ALT_ES_PIN  GPIO_PIN_10

#define AZ_ES_PORT GPIOB
#define AZ_ES_PIN  GPIO_PIN_6

/* az homing search limit, 50-step chunks, about 190 deg */
#define AZ_SEARCH_CHUNKS 135

/* steps from the switch release edge up to laser level */
#define ALT_HOME_OFFSET 0

/* az homing CW search limit, 50-step chunks, about 230 deg */
#define AZ_CW_CHUNKS 164
/* start the final creep this many steps short of the edge, about 4 deg */
#define AZ_CREEP_START 150

/* USER CODE END PD */


/* USER CODE BEGIN PV */


Axis axes[2];
char line_buf[64];
uint8_t line_len = 0;

uint8_t laser_on = 0;
uint32_t laser_on_tick = 0;

/* USER CODE END PV */

void SystemClock_Config(void);
/* USER CODE BEGIN PFP */

void uart_print(const char *s);
int axis_move(Axis *ax, int32_t steps);
void axis_stop_all(void);
void handle_line(const char *line);
void home_altitude(void);
void home_azimuth(void);

/* USER CODE END PFP */

/**
  * @brief  The application entry point.
  * @retval int
  */
int main(void)
{

  /* MCU Configuration--------------------------------------------------------*/

  /* Reset of all peripherals, Initializes the Flash interface and the Systick. */
  HAL_Init();

  /* Configure the system clock */
  SystemClock_Config();

  /* Initialize all configured peripherals */
  MX_GPIO_Init();
  MX_USART2_UART_Init();
  MX_TIM2_Init();
  MX_TIM3_Init();
  /* USER CODE BEGIN 2 */


  axes[0] = (Axis){ &htim3, TIM_CHANNEL_1, DIR1_GPIO_Port, DIR1_Pin, 0, 0, 0, 1 };
  axes[1] = (Axis){ &htim2, TIM_CHANNEL_3, DIR2_GPIO_Port, DIR2_Pin, 0, 0, 0, 1 };
  /* default step period 600us: 3x margin over motor 2's
     unloaded limit (stalls at 150, clean at 200) */
  for (int i = 0; i < 2; i++)
  {
    __HAL_TIM_SET_AUTORELOAD(axes[i].htim, 599);
    __HAL_TIM_SET_COMPARE(axes[i].htim, axes[i].channel, 300);
  }
  uart_print("star pointer ready\r\n");

  HAL_GPIO_WritePin(LASER_PORT, LASER_PIN, GPIO_PIN_RESET);


  /* USER CODE END 2 */

  /* Infinite loop */
  /* USER CODE BEGIN WHILE */
  while (1)
  {
    /* USER CODE END WHILE */

    /* USER CODE BEGIN 3 */


	  if (laser_on && HAL_GetTick() - laser_on_tick >= LASER_TIMEOUT_MS) {
	    HAL_GPIO_WritePin(LASER_PORT, LASER_PIN, GPIO_PIN_RESET);
	    laser_on = 0;
	  }

	  uint8_t c;
	  if (HAL_UART_Receive(&huart2, &c, 1, 0) == HAL_OK) {
	    if (c == '\r' || c == '\n') {
	      if (line_len > 0) {
	        uart_print("\r\n");
	        line_buf[line_len] = '\0';
	        handle_line(line_buf);
	        line_len = 0;
	      }
	    } else if (c == 0x7F || c == 0x08) {
	      if (line_len > 0) {
	        line_len--;
	        uart_print("\b \b");
	      }
	    } else if (line_len < sizeof(line_buf) - 1) {
	      line_buf[line_len++] = c;
	      HAL_UART_Transmit(&huart2, &c, 1, HAL_MAX_DELAY);
	    }
	  }

  }
  /* USER CODE END 3 */
}

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
/* USER CODE BEGIN 4 */

void uart_print(const char *s)
{
  HAL_UART_Transmit(&huart2, (uint8_t *)s, strlen(s), HAL_MAX_DELAY);
}

int axis_move(Axis *ax, int32_t steps)
{
  if (ax->busy) return 1;
  if (steps == 0) return 0;

  ax->dir = (steps > 0) ? 1 : -1;
  HAL_GPIO_WritePin(ax->dir_port, ax->dir_pin,
                    steps > 0 ? GPIO_PIN_SET : GPIO_PIN_RESET);
  ax->steps_left = (steps > 0) ? steps : -steps;
  ax->busy = 1;

  HAL_Delay(1);  /* give DIR time to settle before the first step */

  __HAL_TIM_SET_COUNTER(ax->htim, 0);
  __HAL_TIM_CLEAR_IT(ax->htim, TIM_IT_CC1 | TIM_IT_CC2 | TIM_IT_CC3 | TIM_IT_CC4);
  HAL_TIM_PWM_Start_IT(ax->htim, ax->channel);
  return 0;
}


static int alt_triggered(void)
{
  return HAL_GPIO_ReadPin(ALT_ES_PORT, ALT_ES_PIN) == GPIO_PIN_RESET;
}

static int az_triggered(void)
{
  return HAL_GPIO_ReadPin(AZ_ES_PORT, AZ_ES_PIN) == GPIO_PIN_RESET;
}

/* Blocking move of one axis, used only during homing. */
static int home_step(int32_t steps)
{
  if (axis_move(&axes[0], steps)) return 1;
  while (axes[0].busy) { }
  return 0;
}

void home_altitude(void)
{
  uint32_t saved = __HAL_TIM_GET_AUTORELOAD(axes[0].htim);
  int found = 0;

  /* The cam can only be approached from below: coming down, the lever
     tip catches the clamp slot. So homing always drives up from below. */

  /* if we're already on the cam, back off below it first */
  if (alt_triggered())
  {
    for (int i = 0; i < 80; i++)
    {
      home_step(-50);
      if (!alt_triggered()) { found = 1; break; }
    }
    if (!found) { uart_print("ERR no release\r\n"); goto done; }
    home_step(-100);
    found = 0;
  }

  /* 1. fast approach up until the switch trips */
  __HAL_TIM_SET_AUTORELOAD(axes[0].htim, 1999);
  __HAL_TIM_SET_COMPARE(axes[0].htim, axes[0].channel, 1000);
  for (int i = 0; i < 80; i++)
  {
    home_step(50);
    if (alt_triggered()) { found = 1; break; }
  }
  if (!found) { uart_print("ERR no switch\r\n"); goto done; }

  /* 2. back off below the trip point */
  home_step(-400);
  if (alt_triggered()) { uart_print("ERR stuck on\r\n"); goto done; }

  /* 3. slow approach up to the same edge */
  __HAL_TIM_SET_AUTORELOAD(axes[0].htim, 5999);
  __HAL_TIM_SET_COMPARE(axes[0].htim, axes[0].channel, 3000);
  found = 0;
  for (int i = 0; i < 200; i++)
  {
    home_step(5);
    if (alt_triggered()) { found = 1; break; }
  }
  if (!found) { uart_print("ERR no edge\r\n"); goto done; }

  /* 4. the first trip coming up is level */
  axes[0].pos = 0;
  uart_print("HOMED\r\n");

done:
  __HAL_TIM_SET_AUTORELOAD(axes[0].htim, saved);
  __HAL_TIM_SET_COMPARE(axes[0].htim, axes[0].channel, (saved + 1) / 2);
}

/* Blocking move of any axis, used during homing. */
static void move_wait(Axis *ax, int32_t steps)
{
  while (ax->busy) { }
  axis_move(ax, steps);
  while (ax->busy) { }
}

static void set_period(Axis *ax, uint32_t us)
{
  __HAL_TIM_SET_AUTORELOAD(ax->htim, us - 1);
  __HAL_TIM_SET_COMPARE(ax->htim, ax->channel, us / 2);
}

void home_azimuth(void)
{
  Axis *az = &axes[1];
  uint32_t saved = __HAL_TIM_GET_AUTORELOAD(az->htim) + 1;
  int found;
  int32_t edge;
  char buf[32];

  /* Positive is CW. Home is where the switch RELEASES going CCW off the
     steep ramp. Going CW the switch doesn't click until partway onto the
     flat top, so that edge isn't used. */
  set_period(az, 2000);

  /* 1. if off, go CW until it clicks on */
  if (!az_triggered())
  {
    found = 0;
    for (int i = 0; i < AZ_CW_CHUNKS; i++)
    {
      move_wait(az, 50);
      if (az_triggered()) { found = 1; break; }
    }
    if (!found) { uart_print("ERR no switch\r\n"); goto done; }
  }

  /* 2. fast CCW until it releases, remember roughly where */
  found = 0;
  for (int i = 0; i < AZ_SEARCH_CHUNKS; i++)
  {
    move_wait(az, -50);
    if (!az_triggered()) { found = 1; break; }
  }
  if (!found) { uart_print("ERR no release\r\n"); goto done; }
  edge = az->pos;

  /* 3. back CW until it clicks on again, so the final approach
        is always CCW from the on side */
  found = 0;
  for (int i = 0; i < AZ_CW_CHUNKS; i++)
  {
    move_wait(az, 50);
    if (az_triggered()) { found = 1; break; }
  }
  if (!found) { uart_print("ERR no retrip\r\n"); goto done; }

  /* 4. fast CCW to just short of the edge, then creep one step at a time */
  move_wait(az, (edge + AZ_CREEP_START) - az->pos);
  if (!az_triggered()) { uart_print("ERR lost switch\r\n"); goto done; }

  set_period(az, 6000);
  found = 0;
  for (int i = 0; i < 2000; i++)
  {
    move_wait(az, -1);
    if (!az_triggered()) { found = 1; break; }
  }
  if (!found) { uart_print("ERR no edge\r\n"); goto done; }

  snprintf(buf, sizeof(buf), "HOMED %ld\r\n", (long)az->pos);
  az->pos = 0;
  uart_print(buf);

done:
  set_period(az, saved);
}

void axis_stop_all(void)
{

	  HAL_GPIO_WritePin(LASER_PORT, LASER_PIN, GPIO_PIN_RESET);


  for (int i = 0; i < 2; i++)
  {
    __disable_irq();
    HAL_TIM_PWM_Stop_IT(axes[i].htim, axes[i].channel);
    axes[i].steps_left = 0;
    axes[i].busy = 0;
    __enable_irq();
  }
}

/* Runs automatically at the end of every step pulse */
void HAL_TIM_PWM_PulseFinishedCallback(TIM_HandleTypeDef *htim)
{
  for (int i = 0; i < 2; i++)
  {
    Axis *ax = &axes[i];
    if (htim == ax->htim && ax->busy)
    {
      if (ax->steps_left > 0) ax->steps_left--;
      ax->pos += ax->dir;
      if (ax->steps_left == 0)
      {
        HAL_TIM_PWM_Stop_IT(ax->htim, ax->channel);
        ax->busy = 0;
      }
    }
  }
}

void handle_line(const char *line)
{
  int axis;
  long steps;
  long us;
  char buf[64];

  if (sscanf(line, "M %d %ld", &axis, &steps) == 2)
  {
    if (axis < 1 || axis > 2) { uart_print("ERR bad axis\r\n"); return; }
    if (axis_move(&axes[axis - 1], steps)) { uart_print("ERR busy\r\n"); return; }
    uart_print("OK\r\n");
  }
  else if (strcmp(line, "S") == 0)
  {
    snprintf(buf, sizeof(buf), "POS %ld %ld BUSY %d %d\r\n",
             (long)axes[0].pos, (long)axes[1].pos,
             axes[0].busy, axes[1].busy);
    uart_print(buf);
  }
  else if (strcmp(line, "X") == 0)
  {
    axis_stop_all();
    uart_print("OK\r\n");
  }
  else if (sscanf(line, "V %ld", &us) == 1)
  {
    if (us < 100 || us > 20000) { uart_print("ERR bad period\r\n"); return; }
    if (axes[0].busy || axes[1].busy) { uart_print("ERR busy\r\n"); return; }
    for (int i = 0; i < 2; i++)
    {
      __HAL_TIM_SET_AUTORELOAD(axes[i].htim, us - 1);
      __HAL_TIM_SET_COMPARE(axes[i].htim, axes[i].channel, us / 2);
    }
    uart_print("OK\r\n");
  }

  else if (strcmp(line, "L 1") == 0)
  {
    HAL_GPIO_WritePin(LASER_PORT, LASER_PIN, GPIO_PIN_SET);
    laser_on = 1;
    laser_on_tick = HAL_GetTick();
    uart_print("OK\r\n");
  }
  else if (strcmp(line, "L 0") == 0)
  {
    HAL_GPIO_WritePin(LASER_PORT, LASER_PIN, GPIO_PIN_RESET);
    laser_on = 0;
    uart_print("OK\r\n");
  }


  else if (strcmp(line, "E") == 0)
  {
    snprintf(buf, sizeof(buf), "ES ALT %d AZ %d\r\n",
             alt_triggered(), az_triggered());
    uart_print(buf);
  }


  else if (strcmp(line, "H") == 0)
  {
    home_altitude();
  }

  else if (strcmp(line, "H AZ") == 0)
  {
    home_azimuth();
  }



  else
  {
    uart_print("ERR unknown\r\n");
  }
}

/* USER CODE END 4 */
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


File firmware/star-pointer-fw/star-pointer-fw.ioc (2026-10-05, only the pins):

Mcu.UserName=STM32F401RETx
PA10.Signal=GPIO_Input
PA13.GPIO_Label=TMS
PA13.Signal=SYS_JTMS-SWDIO
PA14.GPIO_Label=TCK
PA14.Signal=SYS_JTCK-SWCLK
PA2.GPIO_Label=USART_TX
PA2.Signal=USART2_TX
PA3.GPIO_Label=USART_RX
PA3.Signal=USART2_RX
PA5.GPIO_Label=LD2 [Green Led]
PA5.Signal=GPIO_Output
PA8.GPIO_Label=DIR2
PA8.Signal=GPIO_Output
PA9.Signal=GPIO_Output
PB10.Signal=S_TIM2_CH3
PB3.GPIO_Label=SWO
PB3.Signal=SYS_JTDO-SWO
PB4.Signal=S_TIM3_CH1
PB5.GPIO_Label=DIR1
PB5.Signal=GPIO_Output
PB6.Signal=GPIO_Input
PC13-ANTI_TAMP.GPIO_Label=B1 [Blue PushButton]
PC13-ANTI_TAMP.Signal=GPXTI13
PC14-OSC32_IN.Signal=RCC_OSC32_IN
PC15-OSC32_OUT.Signal=RCC_OSC32_OUT

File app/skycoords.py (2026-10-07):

"""
skycoords.py - RA/Dec to Alt/Az conversion for the star pointer.

Takes a star's catalog coordinates, my location, and the current time, and
works out where the mount should point. Standard library only.

Pipeline for one target:
    catalog RA/Dec (J2000)
      -> precess to epoch of date
      -> hour angle from local sidereal time
      -> altitude / azimuth for the observer
      -> add atmospheric refraction

Sign conventions:
    latitude   +north
    longitude  +east   (Wylie, TX is about -96.5)
    azimuth    0 = true north, increasing eastward (N=0, E=90, S=180, W=270)
    altitude   0 = horizon, +90 = zenith
"""

from __future__ import annotations

import math
from dataclasses import dataclass
from datetime import datetime, timezone

J2000 = 2451545.0
SECONDS_PER_DAY = 86400.0


# ---------------------------------------------------------------------------
# Time
# ---------------------------------------------------------------------------

def julian_date(when_utc: datetime) -> float:
    """
    Julian Date from a timezone-aware UTC datetime.

    Turns a calendar date into a single number, counting days elapsed since
    noon on Jan 1, 4713 BC. That start point is arbitrary, it is just what
    astronomers settled on. The reason to bother is that calendars are awkward
    for arithmetic: months have different lengths and leap years have rules
    with exceptions. Julian dates make date math subtraction.

    Anchor point: noon UTC on Jan 1, 2000 is exactly JD 2451545.0.
    """
    if when_utc.tzinfo is None:
        raise ValueError("datetime must be timezone-aware; use timezone.utc")
    t = when_utc.astimezone(timezone.utc)

    y, m = t.year, t.month
    # Jan and Feb count as months 13 and 14 of the previous year, which puts
    # leap day at the end where it does not disturb the formula
    if m <= 2:
        y -= 1
        m += 12

    a = y // 100
    b = 2 - a + a // 4  # Gregorian correction: century years are not leap
                        # years unless divisible by 400

    day_fraction = (
        t.day
        + (t.hour + t.minute / 60.0 + (t.second + t.microsecond / 1e6) / 3600.0) / 24.0
    )

    return (
        math.floor(365.25 * (y + 4716))
        + math.floor(30.6001 * (m + 1))
        + day_fraction
        + b
        - 1524.5
    )


def gmst_degrees(jd: float) -> float:
    """
    Greenwich Mean Sidereal Time in degrees.

    Which right ascension is currently crossing overhead at Greenwich.

    The key number is 360.98564736629, the degrees the sky turns per day. It
    is not 360 because the extra 0.986 is Earth's daily orbital motion around
    the Sun. That is the four minute difference between a solar day and a
    sidereal day. The remaining terms are small long-term corrections.

    Formula from Meeus, Astronomical Algorithms.
    """
    d = jd - J2000
    t = d / 36525.0
    gmst = (
        280.46061837
        + 360.98564736629 * d
        + 0.000387933 * t * t
        - (t * t * t) / 38710000.0
    )
    return gmst % 360.0


def lst_degrees(jd: float, longitude_deg: float) -> float:
    """
    Local Mean Sidereal Time in degrees.

    Greenwich sidereal time plus my longitude. I am 96.5 degrees west, so I
    see a given star about 6.4 hours after Greenwich does. Longitude is
    positive east, so Texas is negative.
    """
    return (gmst_degrees(jd) + longitude_deg) % 360.0


# ---------------------------------------------------------------------------
# Precession (J2000 -> epoch of date)
# ---------------------------------------------------------------------------

def precess_from_j2000(ra_deg: float, dec_deg: float, jd: float) -> tuple[float, float]:
    """
    Rotate J2000 catalog coordinates to the mean equinox of date.

    Catalog coordinates are frozen at the year 2000. Earth's axis wobbles like
    a slow spinning top, one full circle every 26,000 years, so the coordinate
    grid itself drifts and a star's listed position goes stale. It is not
    wrong, it is correct for 2000 and out of date for now.

    26 years of drift is 0.15 to 0.37 degrees depending on where the star
    sits, which against a +/-0.5 degree budget takes up most of it.

    The three angles zeta, z and theta describe how much the grid rotated.
    This function applies that rotation. The numbers are the IAU 1976 model.
    """
    t = (jd - J2000) / 36525.0

    zeta = math.radians(0.6406161 * t + 0.0000839 * t * t + 0.0000050 * t ** 3)
    z = math.radians(0.6406161 * t + 0.0003041 * t * t + 0.0000051 * t ** 3)
    theta = math.radians(0.5567530 * t - 0.0001185 * t * t - 0.0000116 * t ** 3)

    ra = math.radians(ra_deg)
    dec = math.radians(dec_deg)

    a = math.cos(dec) * math.sin(ra + zeta)
    b = (
        math.cos(theta) * math.cos(dec) * math.cos(ra + zeta)
        - math.sin(theta) * math.sin(dec)
    )
    c = (
        math.sin(theta) * math.cos(dec) * math.cos(ra + zeta)
        + math.cos(theta) * math.sin(dec)
    )

    ra_out = math.degrees(math.atan2(a, b) + z) % 360.0
    dec_out = math.degrees(math.asin(max(-1.0, min(1.0, c))))
    return ra_out, dec_out


# ---------------------------------------------------------------------------
# Refraction
# ---------------------------------------------------------------------------

def refraction_degrees(apparent_alt_deg: float) -> float:
    """
    Atmospheric refraction, in degrees.

    The atmosphere bends starlight as it enters, so stars look higher than
    they actually are. Half a degree at the horizon, about 0.02 degrees at 45
    degrees altitude, essentially nothing overhead.

    Half a degree is the width of the full moon. When you watch a sunset, the
    Sun has already geometrically set by the time you see it touch the
    horizon.

    Bennett's formula is an empirical fit, not derived from physics. Returns 0
    below the horizon.
    """
    if apparent_alt_deg < -1.0:
        return 0.0
    h = apparent_alt_deg
    arcmin = 1.0 / math.tan(math.radians(h + 7.31 / (h + 4.4)))
    return arcmin / 60.0


# ---------------------------------------------------------------------------
# Observer and the main transform
# ---------------------------------------------------------------------------

@dataclass(frozen=True)
class Observer:
    latitude_deg: float      # +north
    longitude_deg: float     # +east
    name: str = ""


@dataclass(frozen=True)
class Target:
    altitude_deg: float
    azimuth_deg: float

    @property
    def visible(self) -> bool:
        return self.altitude_deg > 0.0

    def __str__(self) -> str:
        state = "up" if self.visible else "below horizon"
        return f"alt {self.altitude_deg:+7.3f}  az {self.azimuth_deg:7.3f}  ({state})"
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

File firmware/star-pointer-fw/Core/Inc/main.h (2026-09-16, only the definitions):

#define B1_Pin GPIO_PIN_13
#define B1_GPIO_Port GPIOC
#define USART_TX_Pin GPIO_PIN_2
#define USART_TX_GPIO_Port GPIOA
#define USART_RX_Pin GPIO_PIN_3
#define USART_RX_GPIO_Port GPIOA
#define LD2_Pin GPIO_PIN_5
#define LD2_GPIO_Port GPIOA
#define DIR2_Pin GPIO_PIN_8
#define DIR2_GPIO_Port GPIOA
#define TMS_Pin GPIO_PIN_13
#define TMS_GPIO_Port GPIOA
#define TCK_Pin GPIO_PIN_14
#define TCK_GPIO_Port GPIOA
#define SWO_Pin GPIO_PIN_3
#define SWO_GPIO_Port GPIOB
#define DIR1_Pin GPIO_PIN_5
#define DIR1_GPIO_Port GPIOB

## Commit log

2026-09-09 Added project structure and design docs
    README describing what I'm building and how it's split between the laptop and STM32, decision log with 6 entries, error budget, and parts list.
    [main.c]
2026-09-15 Regenerate firmware project with CubeMX and add LD2 blink
    Deleted the empty CubeIDE project and regenerated it in standalone CubeMX for the Nucleo-F401RE. New project has HAL drivers, default pin setup, and the .ioc config file. Added a blink on LD2 to conf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
2026-09-15 Add STEP/DIR pins and first stepper test
    Added STEP (PB4) and DIR (PB5) as GPIO outputs in CubeMX. Replaced the LD2 blink with a bit-banged stepper test, one revolution forward and back at 5ms per step. Added bench notes for the first stepper test.
    [main.c, main.h, star-pointer-fw.ioc]
2026-09-15 Add second stepper and step_motor function
    Added STEP2 (PB10) and DIR2 (PA8) in CubeMX and renamed the first motor's pins to STEP1 and DIR1. Moved the step loop into a step_motor() function and tested both motors one revolution forward and ba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
2026-09-15 Add serial control of both motors
    Nucleo now listens on USART2 through the ST-Link USB at 115200 baud. Keys 1 to 4 move each motor forward or backward one revolution and the Nucleo replies with what it did. Added a uart_print() helpe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
2026-09-16 Move step pulses to hardware timers
    Replaced the bit-banged step loop with PWM on TIM3 CH1 (PB4) and TIM2 CH3 (PB10). An interrupt at the end of each pulse counts down steps and stops the timer at zero, so both motors can move at once and the Nucleo keeps reading commands mid-move. Each motor is an Axis struct. Added bench notes for the timer test.
    [main.c, main.h, star-pointer-fw.ioc]
2026-09-16 Add serial command protocol
    Firmware reads full lines over UART with echo and backspace. Added M (move axis by steps), S (position and busy status), and X (stop both axes), with OK/ERR replies. Position is counted in the step i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
2026-09-16 Add Python serial interface
    Added app/mount.py, which wraps the firmware's M, S, and X commands as a Python class with move, status, stop, and wait. Clears the firmware line buffer on connect to avoid desync. Added bench notes for the test.
    [mount.py]
2026-09-16 Switch drivers to 1/16 microstepping
    Wired M2 high and M0/M1 low on both DRV8825s. Moved 3V3 to its own rail to feed SLEEP and M2 on both drivers. Confirmed 3200 steps per motor revolution on both motors. Added bench notes.
2026-09-21 Add printed fits and lazy susan measurements
    Recorded fit-test coupon results from the Bambu P2S, lazy susan bolt circles from printed test rings, ring seam diameters, and pulley tooth band positions.
2026-09-21 Add base hardware measurements
    Recorded caliper measurements for motors, bearings, shaft, pulleys, lazy susan, endstops, and laser.
2026-09-21 Add lazy susan stack test results
    Assembled the printed lid section, spacer, and turntable with the real lazy susan using M5 x 25 countersunk screws. Confirmed both bolt circles, free rotation, and inner screw access from below.
2026-09-21 Add 608 bearing housing test results
    Bearing seats by hand in the 22.0 pocket, spins freely after the retainer is fitted, and the shoulder clears the seal.
2026-09-21 Add degree-based pointing
    Added app/pointer.py to convert altitude/azimuth in degrees to step targets for both axes. Azimuth is kept within -180 to 180 of home to protect the cable loop, altitude is limited to 0 to 90. Tested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
2026-09-21 Point at stars by name
    Added point_at to Pointer, which looks up a star in skycoords, converts to alt/az for Wylie at the current time, and moves both axes. Refuses stars below the horizon. Tested with Vega, Arcturus, and 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
2026-09-22 Add adjustable step speed
    Added V command to set step period live. Tested unloaded limits on both motors and set a 600us default at startup, 3x margin over the weaker motor. Moves are about 7x faster than before.
2026-09-22 Add fork stage assembly results
    Assembled the gusseted fork, bearings, motor plate, and 196mm turntable on the lazy susan. Shaft turns freely with feet tight, pulley tooth bands align, no visible upright flex.
2026-09-23 Add laser control command
    Added L 1 and L 0 to switch the laser through PA9. Pin starts low and is driven low by the stop command, so the beam cannot be left on accidentally. Verified pin levels with a multimeter. Transistor 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
2026-09-23 Add laser cradle fit results
    Cradle clamps the rod and holds the laser using the tested bores. Full 360 rotation with no interference. Screw lengths to be shortened.
2026-09-23 Add altitude home assembly notes
    Installed the home bracket, adjustable switch carrier, and shaft cam on the left upright. Working, but the carrier stays adjustable until the switch's real trip and release points are measured.
2026-09-23 Add endstop switch measurements
    Recorded lever travel, trip point, and overtravel for the endstop switches, which set the cam lift and carrier height for homing.
2026-09-23 Add altitude drive powered test
    Belt fitted and altitude axis driven under power. 3200 steps gives 90 degrees as designed, and out-and-back returns to the same position with no skipped teeth.
2026-09-23 Add endstop state reporting
    Added E command reporting the altitude endstop on PA10. Wired through the endstop board's S/G/V header with the logic inverted to match. Verified both states.
    [main.c, star-pointer-fw.ioc]
2026-09-24 Add altitude homing
    Added H command that homes the altitude axis upward to the cam edge, with a slow final approach and bounded searches. Cam phased so the switch trips at level. Repeatable across runs.
2026-10-05 Fix azimuth endstop pin and note cam shortfall
    Azimuth endstop was configured on PB2, but D10 on this board is PB6. Moved to PB6 and E now reports both axes. Also found a loose 3V3 feed, and the cam lobe is about 1mm short of tripping the switch, so it is being reprinted.
    [main.c, star-pointer-fw.ioc]
2026-10-05 Az homing, cam sweep script, bench notes
2026-10-06 Half-turn az cam, fixed az motor plate, CAD files, bench notes
    [assembly.step, az-home-cam.stl, az-motor-plate.stl]
2026-10-06 Wire laser, drop az switch homing
    Laser switched through a 2N2222 with a 330 ohm base resistor, verified L 1, L 0, and X. Az zero is now a manual index mark; H AZ kept as a test tool. Added cam mapping scripts and bench notes.
2026-10-06 Laser auto-off, wall test results
    Laser turns off 60 s after the last L 1. Wall test at 2.9 m: step scale correct on both axes, backlash under 0.01 deg.
    [main.c]
2026-10-06 Jog controls and laser toggle in web app
    Arrow pad with 5, 1, 0.1 deg and single-step sizes. Laser toggle stays alive while the page is open; firmware auto-off kills it within 60 s if the page goes away. Sets V 2000 on connect.
2026-10-06 Two-star alignment
    Solves base tilt, az offset, and alt zero from two stars; every goto is corrected. Desk test with a simulated tilted mount lands within 0.02 deg. Web app gets an Align section; Ctrl-C now turns the laser off.
    [align.py, pointer.py, web.py]
2026-10-07 First on-sky GOTO
    Aligned on Altair and Vega in the driveway, then hit Deneb, Polaris, and Vega with no correction. Fixed a slipping az pulley found on the first attempt.
2026-10-07 Refresh docs to match working prototype
    README gets setup, usage, and results sections. Adds serial protocol doc and decision D7 on dropping switch homing. Error budget gets measured backlash.
2026-10-07 Accuracy logging, any-angle startup, partner ranking
    Centered button logs GOTO misses to data/accuracy.csv with RMS and worst miss. Alignment no longer needs the laser flat at startup. After the first alignment star, the list ranks partners by how much a centering slip would throw off other GOTOs.
    [align.py, pointer.py, web.py]
2026-10-07 Expand catalog to 82 bright stars
    Every star brighter than mag 3.5 that rises 15 deg above a Texas horizon, with constellation and magnitude, loaded from stars.csv. Precession check now compares every star to the 50.29 arcsec/yr rule.
    [stars.csv]
2026-10-13 Remove wiring layout link until KiCad schematic is done
2026-10-14 v2 assembled: alt sign flip, bench notes and photos
2026-10-14 Add v2 CAD: print files, STEP, assembly, parts list
2026-10-15 Docs audit: BOM, wiring table, firmware build steps, stale details
2026-10-15 Add v1 vs v2 mount comparison

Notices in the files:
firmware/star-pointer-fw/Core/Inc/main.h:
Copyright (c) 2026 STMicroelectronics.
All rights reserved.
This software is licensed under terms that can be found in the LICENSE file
